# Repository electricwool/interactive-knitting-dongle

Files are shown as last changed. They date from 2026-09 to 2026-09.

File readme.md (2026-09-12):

a cheap dongle for interactive knitting

nano

simply wire a magnetic reed sensor from A1 to GND on any development board

tested on generic arduino nano boards with both FT232RL and CH340 serial chips

For australian users these can be purchased from Jaycar although the parts can be found significantly cheaper from chinese sellers.

https://www.jaycar.com.au/miniature-glass-reed-switch/p/SM1002

https://www.jaycar.com.au/arduino-compatible-nano-board/p/XC4414

The 3D printed case takes 4mm M2 screws and threaded inserts

note on positioning the sensor:

magnetic reed switches pickup the magnet on the tips of the wires and on the main sensor body. it also worked by angling the sensor out to the side on the board with smooth curves but it causes it to require a minimum clearance from the sensor to avoid false triggers on the ends of the leads. too close and it will trigger 3x each pass. each kink in the sensor leads will create an extra pickup. ideally the sensor should be installed at a right angle to the edge of the board so that there is only one pickup. the arduino sketch can be adjusted to use A6 as shown in the picture but the specific analog pin is arbitrary. future planning is to use a linear hall sensor for magnet detection due to the fragility of the thin glass capsule of a reed sensor and difficulty bending the wires to fit in the compact profile.

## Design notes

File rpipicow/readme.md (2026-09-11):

This is the rpipicow version

full serial download and interactive knitting support with designaknit and img2track via FTDI emulation

finished

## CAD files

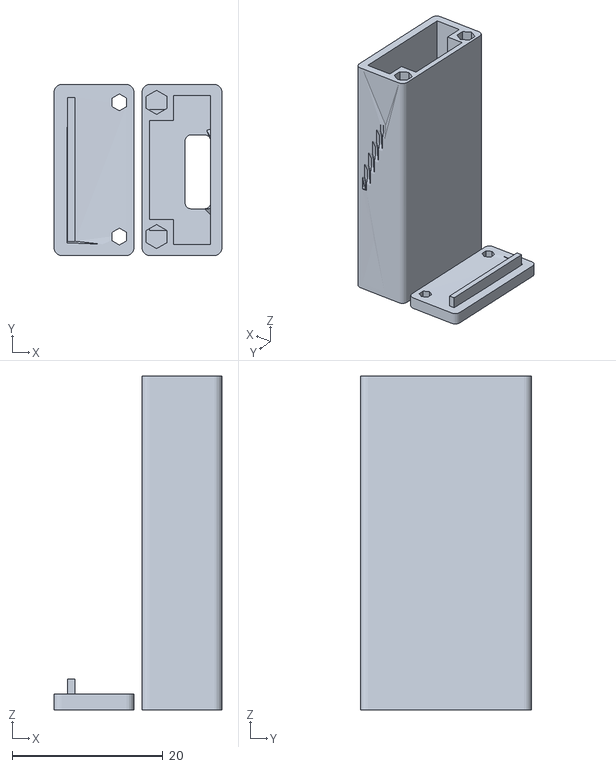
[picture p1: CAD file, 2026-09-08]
interactive nano case combo.stl
22.3 x 22.7 x 44.3

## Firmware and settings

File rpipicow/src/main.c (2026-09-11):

/*
 * main.c — rpipicow firmware.
 *
 * Boot order:
 *   1. level shifter enable (GP6 high),
 *   2. carriage-pass reed sensor (GP27, pull-up, debounced),
 *   3. machine UART link + router,
 *   4. FTDI FT232R emulation (owns the machine link at startup).
 *
 * The main loop drives the USB stack, drains the machine link into the router,
 * pumps the FTDI host->machine path, and turns reed events into BL5
 * carriage-pass bytes for DesignaKnit.
 */

#include "pico/stdlib.h"
#include "tusb.h"

#include "board_config.h"
#include "ftdi.h"
#include "reed_sensor.h"
#include "uart_link.h"
#include "uart_router.h"

int main(void) {
    // 1) Level shifter power first: hold GP6 high so the 3.3V <-> 5V converter
    //    is stable before any other I/O happens.
    gpio_init(PIN_LEVEL_SHIFT_EN);
    gpio_set_dir(PIN_LEVEL_SHIFT_EN, GPIO_OUT);
    gpio_put(PIN_LEVEL_SHIFT_EN, 1);

    // 2) Carriage-pass reed sensor (internal pull-up, debounced).
    reed_sensor_init();

    // 3) Machine UART link + router.
    static uart_link_t machine_link;
    uart_link_config_t link_cfg = {
        .inst     = BOARD_UART_INST,
        .tx_pin   = PIN_UART_TX,
        .rx_pin   = PIN_UART_RX,
        .baud     = BOARD_UART_BAUD,
        .inverted = BOARD_UART_INVERTED,
    };
    uart_link_init(&machine_link, &link_cfg);
    uart_router_init(&machine_link);

    // 4) FTDI FT232R emulation.
    tusb_init();
    ftdi_init();

    while (true) {
        tud_task();          // USB device stack (control + bulk transfers)
        uart_router_poll();  // machine RX -> owner + sniffers
        ftdi_task();         // host -> machine

        if (reed_sensor_task() == REED_EVT_PASS) {
            ftdi_carriage_pass();
        }
    }

    return 0;
}

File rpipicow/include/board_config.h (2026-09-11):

#pragma once
/*
 * board_config.h — single source of truth for pin assignments and link settings.
 *
 * Edit this file to move pins around. Nothing else in the firmware hard-codes
 * pin numbers.
 */

#include "hardware/uart.h"

// ---- Level shifter enable --------------------------------------------------
// GP6 is held HIGH from the moment firmware starts so the 3.3V <-> 5V
// voltage-level converter is powered before any UART traffic exists.
#define PIN_LEVEL_SHIFT_EN      6

// ---- Knitting-machine UART (hardware UART1, inverted 9600 8N1) -------------
// Standard UART1 mapping: GP4 = TX -> machine RX, GP5 = RX <- machine TX.
// (The machine-side wires are swapped so its TX lands on GP5.)
#define PIN_UART_TX             4
#define PIN_UART_RX             5
#define BOARD_UART_INST         uart1
#define BOARD_UART_BAUD         9600
// Brother KH-9xx UART is inverted (idle LOW); applied via GPIO output/input
// overrides inside uart_link.c. The machine also REQUIRES its RTS pin (the
// "green wire" of the official cable, machine connector pin 3) to be held at
// 5 V, or its serial port stays silent (download error 1 / RX reads 0x00).
#define BOARD_UART_INVERTED     1

// ---- Carriage-pass reed sensor ---------------------------------------------
// Reed switch wired between GP27 and GND. The internal pull-up keeps the line
// HIGH until a magnet closes the reed and pulls the line LOW.
#define PIN_REED_SENSOR         27
#define REED_ADC_CHANNEL        1       // GPIO27 == ADC input 1
#define REED_THRESHOLD_MV       3000    // < 3.0 V  => magnet present
#define REED_DEBOUNCE_MS        10      // LOW must hold this long to count a pass
#define REED_REARM_MS           100     // HIGH must hold this long before re-arming

// ---- UART router -----------------------------------------------------------
#define UART_ROUTER_MAX_CLIENTS 8

// FTDI (machine link) client defaults.
#define UART_ROUTER_FTDI_DEFAULT_OWNER    1   // start owning the machine link
#define UART_ROUTER_FTDI_DEFAULT_LISTENER 0   // don't mirror traffic by default

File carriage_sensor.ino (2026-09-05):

/*
 * DesignaKnit Carriage-Pass Sensor — Arduino Nano v3
 *
 * Emulates the FT230XS carriage-pass sensor described in ../protocol.md.
 *
 * The Arduino Nano enumerates as an FTDI FT232RL USB-serial port. Its TXD
 * pin (PD1) is wired to the FTDI chip's RXD input. Holding that line low
 * for longer than one character frame is reported by the FTDI to the host
 * as a UART "break" plus a received 0x00 byte — the same event DesignaKnit
 * uses to increment the row counter (protocol.md §5–6, "and/or" rule).
 *
 * No serial data is ever transmitted; the ATmega only drives the line.
 *
 * Sensor wiring (analog pin A1):
 *   - internal pull-up enabled
 *   - reed switch (or equivalent) from A1 to GND
 *   - the carriage magnet closes the switch, pulling A1 below 1.0 V
 */

// ---- Pin definitions -------------------------------------------------------
const int SENSOR_PIN = A1;  // analog input A1, internal pull-up active
const int TXD_PIN    = 1;   // ATmega TXD (PD1) -> FTDI RXD input

// ---- Timing / thresholds ---------------------------------------------------
// 1.0 V threshold on a 5 V / 10-bit ADC: 1.0 / 5.0 * 1023 ≈ 205 counts.
// A reading below this means the sensor line is pulled low.
const int THRESHOLD_COUNTS = 205;

const unsigned long DEBOUNCE_MS    = 10;   // low condition must hold this long
const unsigned long REARM_DELAY_MS = 100;  // re-arm 100 ms after the line goes high
const unsigned long BREAK_MS       = 5;    // TX line held low (1 frame @57600 ≈ 174 µs)

enum State : uint8_t {
  ARMED,  // waiting for the next carriage pass
  FIRED   // signal sent; waiting for release + re-arm delay (monostable)
};

State state = ARMED;

unsigned long lowStart  = 0;  // when the line first went low (debounce)
unsigned long highStart = 0;  // when the line first went high (re-arm)

void setup() {
  // TX line idle-high: no break, no 0x00 reported.
  pinMode(TXD_PIN, OUTPUT);
  digitalWrite(TXD_PIN, HIGH);

  // Sensor input with internal pull-up.
  pinMode(SENSOR_PIN, INPUT_PULLUP);
}

void loop() {
  bool isLow = analogRead(SENSOR_PIN) < THRESHOLD_COUNTS;
  unsigned long now = millis();

  switch (state) {
    case ARMED:
      if (isLow) {
        if (lowStart == 0) {
          lowStart = now;
        } else if (now - lowStart >= DEBOUNCE_MS) {
          fireCarriagePass();
          state = FIRED;
          lowStart = 0;
          highStart = 0;
        }
      } else {
        lowStart = 0;  // not a stable low yet
      }
      break;

    case FIRED:
      // Monostable: ignore the sensor until the line has gone back high and
      // stayed high for REARM_DELAY_MS. A carriage parked at the sensor
      // produces exactly one signal, not repeated ones.
      if (isLow) {
        highStart = 0;  // still parked at the sensor; keep waiting
      } else {
        if (highStart == 0) {
          highStart = now;
        } else if (now - highStart >= REARM_DELAY_MS) {
          state = ARMED;
          highStart = 0;
        }
      }
      break;
  }
}

// Emit one carriage-pass event: hold the FTDI RXD line low for BREAK_MS.
// The FTDI reports this to DesignaKnit as break + 0x00 (one row increment).
void fireCarriagePass() {
  digitalWrite(TXD_PIN, LOW);
  delay(BREAK_MS);
  digitalWrite(TXD_PIN, HIGH);
}

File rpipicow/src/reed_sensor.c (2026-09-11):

/*
 * reed_sensor.c — debounced, monostable reed-switch detector.
 *
 * One REED_EVT_PASS per carriage pass, then the line must return HIGH and stay
 * HIGH for REED_REARM_MS before the next pass can be detected (a carriage
 * parked on the sensor produces exactly one event).
 */

#include "reed_sensor.h"
#include "board_config.h"

#include "hardware/gpio.h"
#include "pico/stdlib.h"
#include "pico/time.h"

typedef enum {
    ARMED,   // waiting for the next pass
    FIRED    // pass signalled; waiting for release + re-arm
} reed_state_t;

static reed_state_t s_state = ARMED;
static uint32_t s_low_start = 0;    // ms timestamp when the line first went low
static uint32_t s_high_start = 0;   // ms timestamp when the line first went high

void reed_sensor_init(void) {
    gpio_init(PIN_REED_SENSOR);
    gpio_set_dir(PIN_REED_SENSOR, GPIO_IN);
    gpio_pull_up(PIN_REED_SENSOR);
    gpio_set_input_enabled(PIN_REED_SENSOR, true);
}

reed_event_t reed_sensor_task(void) {
    // Line LOW == magnet present (reed closed to GND).
    bool low = !gpio_get(PIN_REED_SENSOR);
    uint32_t now = to_ms_since_boot(get_absolute_time());

    switch (s_state) {
        case ARMED:
            if (low) {
                if (s_low_start == 0) {
                    s_low_start = now;
                } else if (now - s_low_start >= REED_DEBOUNCE_MS) {
                    s_state = FIRED;
                    s_low_start = 0;
                    s_high_start = 0;
                    return REED_EVT_PASS;
                }
            } else {
                s_low_start = 0;   // not a stable low yet
            }
            break;

        case FIRED:
            if (low) {
                s_high_start = 0;  // carriage still parked on the sensor
            } else {
                if (s_high_start == 0) {
                    s_high_start = now;
                } else if (now - s_high_start >= REED_REARM_MS) {
                    s_state = ARMED;
                    s_high_start = 0;
                    return REED_EVT_RELEASE;
                }
            }
            break;
    }

    return REED_EVT_NONE;
}

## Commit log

2026-09-08 Add 3D printed case screw and insert details
    Added information about the 3D printed case specifications.
2026-09-09 Update readme with sensor positioning notes
    Added notes on sensor positioning and future plans for magnet detection.
2026-09-09 Update readme with sensor installation notes
    Added notes on sensor positioning and future plans for sensor upgrades.
2026-09-12 Revise readme with updated Arduino compatibility
    Updated compatibility information and added image.
